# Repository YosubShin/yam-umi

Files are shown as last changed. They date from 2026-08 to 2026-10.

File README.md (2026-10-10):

# YAM-UMI

An open-source, hand-worn [UMI](https://umi-gripper.github.io/)-style data
collection device for the **[I2RT YAM](https://i2rt.com/products/yam-6-dof-arm)
arm's linear gripper**.

> **Paper and video:**
> [YAM-UMI: A Fiducial-Tracked Glove that Collects Metrically Labelled Demonstrations for the YAM](paper/main.pdf) (preprint) ·
> [2.5-minute video](media/yam-umi-paper-video.mp4) ·
> [LaTeX source and figures](paper/)

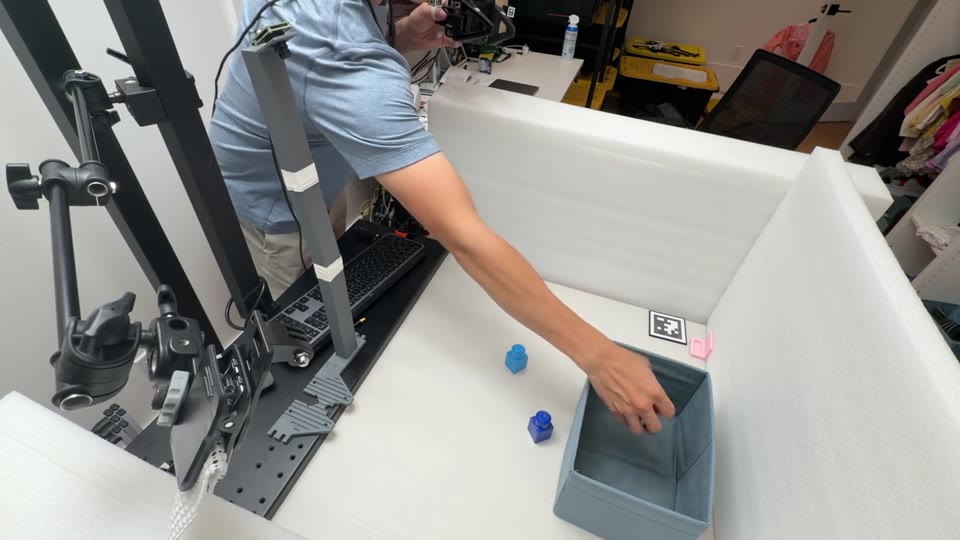
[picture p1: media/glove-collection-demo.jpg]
Glove collection demo with YAM-UMI and experimental tracking accessories


*Watch the [glove collection demo](media/glove-collection-demo.mp4) (63 seconds,
9.4 MB). This setup combines the YAM-UMI gripper with
[forward-cam-umi](https://github.com/YosubShin/forward-cam-umi) marker tails,
the optional dodecahedral wrist tracker, and a head-mounted camera.*

<p align="center">
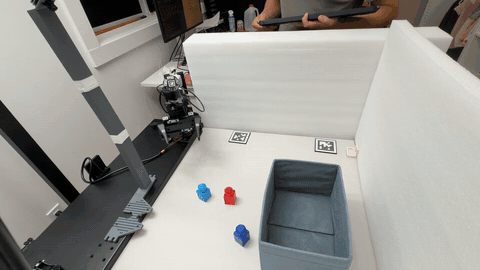
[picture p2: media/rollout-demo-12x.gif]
YAM-UMI rollout demo at 12 times normal speed
  
</p>
<p align="center"><em>Rollout demo at 12× speed (full sequence, about 20 seconds).
Watch the silent 720p video at <a href="media/rollout-demo-1x-720p.mp4">normal speed</a>
or <a href="media/rollout-demo-6x-720p.mp4">6× speed</a>.</em></p>

YAM-UMI is deliberately built for one arm.
It mirrors the YAM linear gripper's jaw geometry, reuses the YAM wrist camera
mount, and reproduces the gripper's own rail-and-pinion mechanism, so **the
camera pose relative to the gripper tips, and the way those tips move, are the
same during data collection as on the deployed robot**. Aperture is recovered
from fiducial markers rather than a servo encoder, so there is no motor to
backdrive and no loaded plastic linkage to fail.

<p align="center">
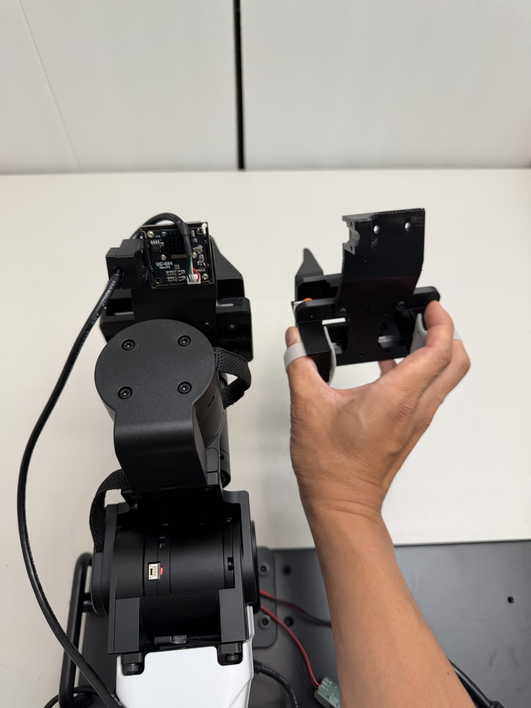
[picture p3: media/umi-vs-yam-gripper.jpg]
The YAM arm's linear gripper beside the YAM-UMI handheld device, showing matched jaw geometry and the same wrist camera mount
  
</p>
<p align="center"><em>Left: the YAM arm's gripper. Right: YAM-UMI. Same jaw geometry,
same camera mount, same tips — so the wrist camera sees the same thing in both.</em></p>

<p align="center">
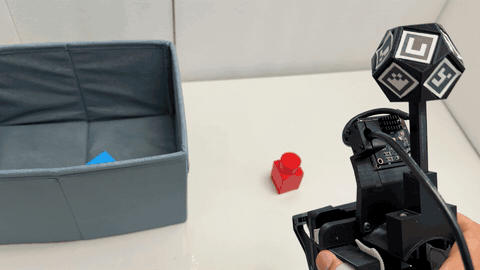
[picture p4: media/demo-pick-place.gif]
Operator performing a pick-and-place with the YAM-UMI gripper, dodecahedral tracker visible above the wrist
  
</p>
<p align="center"><em>Pick-and-place demonstration, with the dodecahedral wrist tracker
attached. Full quality: <a href="media/demo-pick-place.mp4">demo-pick-place.mp4</a>.</em></p>

> **Status: hardware released, pipeline in progress.** The mechanical design is
> printed and assembled, and the optional wrist tracker is characterised for
> settled holds (0.46 mm RMS). End-to-end data collection and policy training with
> this device have not been run yet, and the parity claims below are by
> construction rather than measured — see
> [Status and limitations](#status-and-limitations).

## Why another UMI variant

The point of a UMI-style rig is to collect demonstrations without a robot in the
loop, then train a policy that consumes wrist-camera images. That only works if
what the camera sees at collection time resembles what it sees at deployment
time.

That principle is UMI's own, not this project's. The
[UMI paper](https://arxiv.org/abs/2402.10329) states it directly — *"When
deploying UMI on a robot, we place GoPro cameras with the same location with
respect to the same 3D-printed fingers as on the hand-held gripper"* — and reports
wrist-camera video that is "almost indistinguishable" between demonstration and
deployment.

What differs between designs is the **direction** in which the match is made. UMI
adapts the robot to the interface: mount UMI's fingers and a GoPro on any arm with
a parallel jaw stroke over 85 mm, and the match follows. YAM-UMI adapts the
interface to the robot: the arm keeps its stock gripper tips and stock camera
mount, and the handheld device changes to match. That direction suits a fleet
already standardized on one arm, or a deployment configuration you would rather
not modify — at the cost of fitting nothing else.

This design began as an attempt to use
[HandUMI](https://github.com/murobotics-ai/handumi-hw) on a YAM. HandUMI is one
of the few open hand-worn UMI designs whose linkage keeps the two jaws
**synchronized**, moving together the way a parallel gripper does rather than
independently following the operator's two fingers. For anyone targeting a linear
gripper that property is the hard part, and it made HandUMI the natural starting
point here. Two things kept it from working on a YAM.

### 1. The camera extrinsic could not be matched

HandUMI takes a third position: rather than adapting either side, it keeps one
shared body across arms and swaps only the gripper tips, leaving the rest to
software retargeting. That is what lets a single rig serve an AgileX Piper, an ARX
X5, a Trossen WidowX and others — but it means the wrist camera sits where the
shared body allows, and its mount does not readily adjust to reproduce the YAM
camera's angle relative to the gripper tips. The resulting viewpoint shift is a
domain gap the policy has to absorb.

YAM-UMI instead reuses the YAM gripper's own fisheye camera mount on a body that
reproduces the YAM jaw geometry, so the camera-to-tip transform is matched by
construction rather than corrected in software. Because the device also accepts
the **actual gripper tips that ship with the YAM arm**, the jaws occlude the same
part of the frame, the aperture-to-pixel mapping is the same, and the contact
patch on the object is the same.

The cost is generality: this rig targets the YAM linear gripper and nothing else.
That is a deliberate trade, not an oversight.

### 2. The servo and the lever linkage

HandUMI measures aperture with a Feetech servo encoder, which gives a clean
per-frame width signal. The operator pays for it by backdriving the servo through
its gear train on every pinch, adding friction to the one motion the device
exists to record faithfully.

The linkage was the more immediate problem. In hand, its printed lever parts
popped out of the mechanism under normal use — the load path runs through
printed plastic links, and that is where it failed.

YAM-UMI carries the motion on two MGN9 linear rails instead, with a single pinion
between two racks — one rack per jaw — to keep the jaws synchronized.

**This is the mechanism the YAM gripper itself uses.** Two MGN9 rails, two racks,
and a pinion is not an arbitrary alternative to the crank linkage; it is what is
inside the robot's own linear gripper. So the parity here is not only optical and
geometric but *kinematic*: the jaws travel the way the robot's jaws travel, the
aperture is symmetric about the same centerline, and the relationship between the
operator's pinch and the resulting width is the one the robot can actually
execute. There is no mechanism-level retargeting between collection and
deployment, because there is no mechanism difference to retarget.

Aperture is read from fiducial markers on the tips, the approach the original UMI used.
Consequences:

- **No backdrive friction.** The pinch is governed by the rails and the
  rack-and-pinion coupling only.
- **No servo, controller, or power supply** in the bill of materials, and no
  cable routing for them.
- **No loaded lever linkage.** The printed parts are brackets and mounts, not
  structural links carrying the pinch load.

<p align="center">
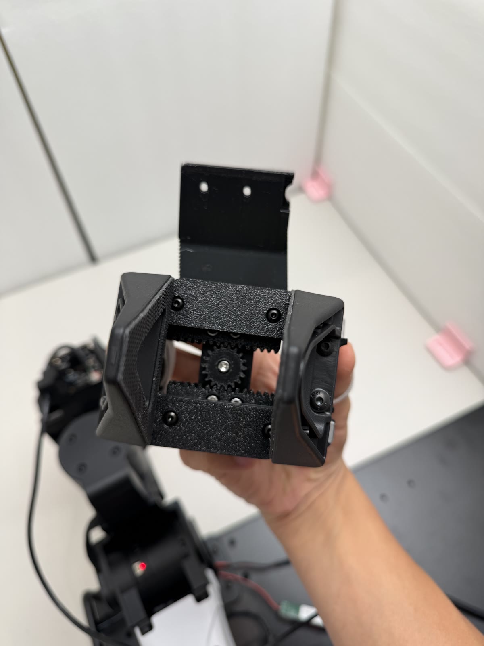
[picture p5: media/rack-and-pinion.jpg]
View from the gripper tip side: a central pinion meshing with a rack on each jaw, keeping the two jaws synchronized
  
</p>
<p align="center"><em>Viewed from the tip side: one pinion between two racks, one rack
per jaw, riding two MGN9 rails — the same arrangement as inside the YAM arm's own
linear gripper. A single-handed pinch drives both jaws symmetrically, with no
servo in the loop and no linkage carrying the load.</em></p>

## What it records

| Signal | Source |
|---|---|
| Wrist pose, SE(3) | Camera SLAM from the wrist fisheye — the original UMI approach, and the default here. Optionally, a dodecahedral ArUco marker ball observed by an external camera |
| Gripper aperture | 6 mm AprilTag (16h5) markers on the gripper tips, seen by the wrist fisheye camera |
| Wrist-view video | Fisheye USB camera on the YAM camera mount |

SLAM is the default because it keeps collection portable, which is the whole
point of a UMI-style rig. The visual-inertial SLAM path does not need the
marker-ball assembly; the wrist-camera tip markers are still used to measure
aperture.

### Optional: dodecahedral wrist tracker

If your setup can accommodate a fixed external camera, this repository also
includes a dodecahedral marker ball and the mounts that attach it to the gripper.
It buys precision at the cost of confining collection to the camera's view.

Measured with the ball at roughly 94 cm standoff, **on settled holds**:

| Metric | Result |
|---|---|
| Within-hold precision | 0.46 mm RMS (median), p90 0.68 mm |
| Revisit repeatability | 0.08–0.17 mm SD per axis (lateral 0.12, depth 0.17) |

Coverage — the fraction of frames with enough faces visible to solve a bundle
pose — depends strongly on the external camera:

| Camera | ≥1 face | ≥2 faces | ≥3 faces |
|---|---|---|---|
| Sony (4K 30p, H.264) | 100% | 90.8% | 77.5% |
| Arducam B0591 (1080p, focus locked via v4l2) | 79.6% | 68.3% | 59.1% |

**Update (2026-09):** both of the original caveats — settled-holds-only, and
absolute pose unresolved — have since been resolved by measuring this same
ball design on the real YAM arm against its joint encoders. During full-speed
teleoperated manipulation (30 episodes, ~23k frames), fused-ball pose agrees
with the robot's forward kinematics to **7.7 mm median / 22.7 mm p95 / 1.7°**
at a tool point 13 cm from the ball, with pose solved in 98.5% of frames;
the error budget is dominated by the hand-eye calibration (4.8 mm residual),
not the camera. The earlier 14%/9° discrepancies were extrinsics error, fixed
by a proper `calibrateRobotWorldHandEye` solve harvested from ordinary
episodes. Full numbers, method, and known failure modes:
[`pos-tracking/dynamic-accuracy.md`](pos-tracking/dynamic-accuracy.md).

The Arducam coverage was measured before any mount or field-of-view tuning for that
camera, so it is a floor rather than a verdict on cheaper webcams.

See [`pos-tracking/README.md`](pos-tracking/README.md) for the build and
calibration procedure.

The third-party [tinyumi Quest-controller mount](https://github.com/vovw/tinyumi/blob/main/pos-tracking/quest_mount/handumi_v1/README.md)
provides an alternative pose source. It requires that fork's revised base plate
and mounting hardware and has not been tested by the YAM-UMI authors.

## Design updates

### 2026-09-28 — L bracket v4 and handle v14

- Updated the L bracket to mitigate plate bending when squeezing the glove hard.
- Changed gripper fastening from M4 bolts and nuts to M4 screws with heat-set
  inserts to make assembly easier.
- Updated the [STEP](hardware/STEP/L_bracket_v4.step) and
  [STL](hardware/STL/L_bracket_v4.stl) files, replacing v3.
- Updated the handle to v14, removing the side hole for an M4 nut. The handle
  attaches to the L plate with an M3 screw and heat-set insert; the remaining
  M4 hole serves only to prevent the handle from rotating in place.
  Updated the [STEP](hardware/STEP/handle_v14.step) and
  [STL](hardware/STL/handle_v14.stl) files, replacing v13.

## Parts

### Gripper body — [`hardware/`](hardware/)

Printed parts are provided as STEP and STL. The STEP files are the source of
truth; the STLs were tessellated from them at 0.05 mm chordal tolerance and are
watertight, so re-export from STEP if you want a different resolution.

| Part | Size (mm) | Role |
|---|---|---|
| `plate_v6` | 102 × 65 × 10.4 | Main plate; carries both linear rails, the camera arm, and the pinion axle |
| `adapter_v10` | 50 × 25.9 × 10.6 | Carriage-to-jaw adapter; presents the YAM gripper tip interface |
| `pinion_z18_deep_v0`–`v3` | ⌀20.0–19.7 × 10.6 | Module 1, z=18 spur pinion coupling the two jaw racks for symmetric motion, as in the YAM gripper. Four fit variants — see [Printing](#printing) |
| `handle_v14` | 32 × 17 × 55 | Operator handle |
| `L_bracket_v4` | — | Camera arm bracket |
| `YAM_linear_gripper_fisheye_camera_mount` | — | Fisheye camera mount, matching the YAM wrist camera pose |

<!-- TODO: confirm the Role column. The pinion/rack coupling is confirmed by the
     tip-side photo, but the plate, adapter, handle and bracket roles are still
     inferred from geometry rather than from your notes. -->

**Gripper tips are not printed.** Use the "Linear 4310" tips that ship with the
YAM arm — that is what makes the contact geometry identical to deployment. If you
do not have spares, I2RT sells them as
[Gripper Tips (for Linear-Gear Style Gripper)](https://i2rt.com/products/gripper-tips-for-linear-gear-style-gripper)
($69), though they are frequently out of stock.

### Position tracking — [`pos-tracking/`](pos-tracking/)

See [`pos-tracking/README.md`](pos-tracking/README.md) for marker specifications
and printing instructions.

- `wrist_dodecahedron_marker/` — the dodecahedral marker ball (51 mm across),
  its stalk, arc adapter, and extender.
- `glove_markers_v4.pdf` — the marker sheet: 15 mm ArUco markers for the ball
  and the 6 mm AprilTag tip markers used for aperture sensing from the wrist
  fisheye camera.

Marker placement on the ball is not prescribed: stick the eleven markers on in
any arrangement and recover the face-to-ID mapping by calibration. That absorbs
print-and-stick tolerances instead of baking them in as permanent error, but it
also means each ball's calibration is specific to the unit it was measured on.

The marker sheet also carries tail and base markers for
[forward-cam-umi](https://github.com/YosubShin/forward-cam-umi), which provide
occlusion backup and external-camera aperture measurements. These require
additional printed parts; see
[optional forward-camera extensions](pos-tracking/README.md#optional-forward-camera-extensions).

## Build

- [Bill of materials](bom/README.md) — ~$79 per gripper in parts, plus shop supplies (filament, fastener kits, tape) if you are starting from nothing.
- [Assembly](docs/assembly.md) — build order and fastener placement.

### Printing

Everything was printed in **PETG** on a Bambu Lab X2D with the stock PETG profile
and *Support for PLA/PETG* enabled. No part needed tuning beyond support
settings. PLA should work too — nothing here runs warm and it is an indoor,
hand-held device — PETG is simply what these were printed in.

**The pinion comes in four variants.** `pinion_z18_deep_v0`–`v3` are the same
18-tooth, module-1 pinion at descending outside diameter — 20.0, 19.9, 19.8 and
19.7 mm — a 0.1 mm clearance ladder against the racks. **Print all four on one
plate and pick the one that runs smoothest** in your assembly. Printer, filament
and insert alignment all shift the effective fit, so the right variant is
empirical rather than predictable; `v3` was the best fit in the reference build,
but choose the variant that runs most smoothly on your unit.

## Status and limitations

- **Glove collection and training:** the companion
  [forward-cam-umi workflow](https://github.com/YosubShin/forward-cam-umi/blob/main/scripts/README.md)
  reports four glove sessions (about 70 episodes) recorded, solved, built into
  training datasets, and used for training. Camera-extrinsic parity remains a
  separate claim that has not been validated against recorded imagery.
- **Wrist tracker: settled-hold precision 0.46 mm RMS at ~94 cm; dynamic
  tracking and absolute robot-frame pose are now certified** (7.7 mm median
  agreement with the arm's forward kinematics across full-speed
  manipulation) — see
  [`pos-tracking/dynamic-accuracy.md`](pos-tracking/dynamic-accuracy.md).
- **Camera and glove-marker calibration:** commands for camera intrinsics,
  ball geometry, and gripper-marker geometry are published in
  [forward-cam-umi](https://github.com/YosubShin/forward-cam-umi/blob/main/scripts/README.md).
  Robot-side hand-eye calibration and dataset construction require the robot's
  kinematics and are separate from this assembly.
- **Aperture accuracy is unmeasured.** A comparison of fiducial-derived width
  against the YAM encoder, or against calipers over a swept aperture, would be
  the most valuable single addition to this repo.
- **Fiducial occlusion** is an inherent failure mode; there is no fallback width
  estimate when markers are lost.
- **Single-arm scope.** No support for other grippers is planned.

## Related work

- **[UMI](https://umi-gripper.github.io/)** (Chi et al.,
  [arXiv:2402.10329](https://arxiv.org/abs/2402.10329)) — the original handheld
  gripper, the source of both the fiducial-based aperture sensing this design
  returns to and the principle of minimizing the observation embodiment gap.
  UMI achieves that match by mounting its own fingers and camera on the robot;
  YAM-UMI reverses the direction.
- **[HandUMI](https://github.com/murobotics-ai/handumi-hw)** (Murobotics) — the
  direct starting point for this work, and one of the few open hand-worn UMI
  designs with a synchronized parallel-jaw mechanism. YAM-UMI takes the
  glove-style form factor and the hook-and-loop finger retention from it, and
  diverges on camera placement, jaw mechanism, and aperture sensing for the
  reasons above. If you want a robot-agnostic rig rather than a YAM-specific one,
  or a direct encoder reading of aperture, HandUMI is the better fit. No HandUMI
  CAD is used here.
- **[Generalist](https://generalistai.com/)** — the wearable data-collection
  approach HandUMI credits as its own motivation.

### The robot this targets

- **[YAM 6-DOF arm](https://i2rt.com/products/yam-6-dof-arm)** (I2RT Robotics) —
  the arm YAM-UMI is built for. 6 DOF, 2 kg payload, 95 mm gripper throw.
- **[YAM documentation](https://doc.i2rt.com/products/yam)** — specifications and
  setup for the arm and its linear gripper.
- **[`i2rt-robotics/i2rt`](https://github.com/i2rt-robotics/i2rt)** — the Python
  client library, URDF, and robot meshes. The meshes there are what this design's
  gripper geometry and camera mount are dimensioned from; see
  [THIRD_PARTY_NOTICES.md](THIRD_PARTY_NOTICES.md).

## License and attribution

This project is released under the [MIT License](LICENSE).

Geometry in this repository is dimensioned from mesh files published by I2RT
Robotics under the MIT License. See
[THIRD_PARTY_NOTICES.md](THIRD_PARTY_NOTICES.md) for the full attribution.

**This project is not affiliated with, endorsed by, or sponsored by I2RT
Robotics.** "YAM" is used only to identify the robot arm this hardware is
designed for.

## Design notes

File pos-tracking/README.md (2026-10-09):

# Position tracking

**This is an optional add-on.** The default way to recover wrist pose with
YAM-UMI is camera SLAM from the wrist fisheye, the same approach the original UMI
used, with visual-inertial SLAM. It needs no marker-ball hardware and keeps
collection portable. The wrist-camera aperture markers described below are
still needed to measure jaw opening.

What is here is a **dodecahedral ArUco marker ball** on a stalk, observed by an
external forward-facing camera, for setups that can accommodate a fixed camera.
It measures sub-millimetre on settled holds (numbers below), at the cost of
confining collection to that camera's view. Ball markers use the
**`DICT_4X4_100`** dictionary, IDs 25–35; IDs 36–49 are for the
forward-camera extension described below. IDs 0–24 are reserved for the
robot-mounted ball used to validate tracking against forward kinematics (see
[forward-cam-umi](https://github.com/YosubShin/forward-cam-umi)).

<p align="center">
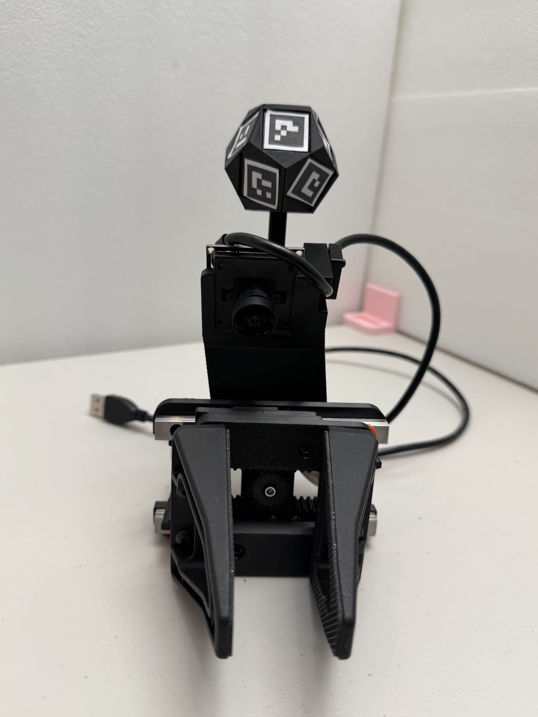
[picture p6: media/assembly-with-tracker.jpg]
The assembled YAM-UMI gripper with the dodecahedral ArUco marker ball mounted on its wrist stalk
  
</p>
<p align="center"><em>The assembled gripper with the dodecahedral tracker on its
stalk, held clear of the hand and of the fisheye camera's view.</em></p>

## Parts

| Part | Size (mm) | Notes |
|---|---|---|
| `dodeca_marker_ball_v2` | 51.05 across | Regular dodecahedron; carries the 15 mm markers |
| `stalk_rod_80mm` | 8 × 8 × 80 | Rod holding the ball clear of the hand |
| `wrist_stalk_arc_adapter` | 44 × 14 × 49.8 | Mounts the stalk to the wrist |
| `arc_extender` | 43.5 × 41.5 × 57 | Extends the arc mount |

A dodecahedron is used so that at least one face is well-conditioned for pose
estimation from any viewing direction, which removes the orientation blind spots
a single planar marker has.

## Markers

`glove_markers_v4.pdf`, group *dodecahedron ball*: **nominal 15 mm black
squares on 19.5 mm tiles, IDs 25–35**, applied to eleven faces of the ball.
Use measured black-square sizes for calibration.

The basic wrist-camera-and-ball assembly uses the sheet's left column:
the *dodecahedron ball* group and the *tips WRIST* group
([below](#aperture-markers)).

### Optional forward-camera extensions

The right-hand column contains the *tails* (BACK, TOP, FORWARD, OUTSIDE,
BOTTOM) and *base* (BACK, TOP) groups, IDs 36–49. They belong to the
[forward-cam-umi extensions](https://github.com/YosubShin/forward-cam-umi):
extra markers and printed parts provide an occlusion backup for the ball
and let the external camera measure aperture. They are not required for
the basic wrist-camera-and-ball assembly. Follow the companion repository
if using those extensions; both projects share this sheet so the marker
IDs do not collide.

### Measure and prepare the markers

Print at **100% / Actual size** on matte paper or label stock, disabling
all automatic scaling. Before cutting, check the 100 mm bar and take
**six black-square measurements per group**, across different markers and
alternating width and height. Average and record each group separately;
the white border is the cutting boundary, not the measurement boundary.
Enter the measured sizes in the unit's marker map and use the measured
ball size in its calibration. See the assembly guide's
[measurement procedure](../docs/assembly.md#measure-before-you-cut--every-marker-group).

Apply thin double-sided tape across the **entire back of the uncut marker
region**, then cut through paper and tape together, preserving the white
border. Bond every edge flat. Do not use glue, glossy paper, or tape over
the printed face: curled edges and reflections interfere with corner
detection. The same preparation applies to ball, finger, and extension
markers.

### Marker placement is not prescribed

There is deliberately **no face-to-ID mapping to follow**. Apply the eleven
markers to the faces in any arrangement, then recover the layout by
running the assembled ball through a solver that estimates each marker's pose in
the ball's body frame from observations across many viewpoints.

This is worth understanding before you build: the ball's geometry is calibrated,
not assumed. It means print-and-stick tolerances are absorbed by the calibration
rather than becoming permanent error, and it means **your ball's mapping will
differ from anyone else's** — the calibration output is specific to the physical
unit you built and has to travel with it.

Follow [forward-cam-umi steps 2–6](https://github.com/YosubShin/forward-cam-umi/blob/main/scripts/README.md)
for camera setup, intrinsics, a rotation take, detection, and ball geometry
solving. Use the measured marker size and keep the solved geometry with
that physical ball. Moving, re-sticking, or swapping a marker requires
recalibrating it. The assembly guide summarizes the
[camera and calibration sequence](../docs/assembly.md#the-forward-camera-mount-focus-calibrate-solve-the-ball).

### Measured performance

All figures below were taken with the ball at roughly 94 cm standoff from the
external camera, **on settled holds**.

**Precision**

| Metric | Result |
|---|---|
| Within-hold | 0.46 mm RMS (median), p90 0.68 mm |
| Revisit repeatability | 0.08–0.17 mm SD per axis (lateral 0.12, depth 0.17) |

**Coverage** — the fraction of frames with enough faces visible to solve a bundle
pose. This is where the choice of external camera shows up:

| Camera | ≥1 face | ≥2 faces | ≥3 faces |
|---|---|---|---|
| Sony (4K 30p, H.264) | 100% | 90.8% | 77.5% |
| Arducam B0591 (1080p, focus locked via v4l2) | 79.6% | 68.3% | 59.1% |

The B0591 numbers were measured before any mount or field-of-view tuning for
that camera. The 15 mm faces give it comfortable pixels at this range, so the
gap to the Sony is a field-of-view and mounting difference rather than a
sensor limit — treat 68% as a floor, not a verdict on cheaper webcams.

#### The camera that ended up winning: Arducam B0587 (4K low-light)

After the table above we moved to the **Arducam B0587** (4K STARVIS2 sensor,
~88° FOV, UVC/MJPEG) and it became the workhorse — it is the camera behind
every number in [`dynamic-accuracy.md`](dynamic-accuracy.md):

| Metric | Result |
|---|---|
| ChArUco intrinsics | 0.744 px RMS at 4K |
| Rigid marker-pair RMS (best pairs) | 0.7 mm |
| Detection vs arm speed | flat to 3 m/s — no measured ceiling |
| Per-frame ≥1-face detection, full teleop session | 99.97% |

**Why it works — the motion-blur unlock.** Fiducial tracking during motion
dies by corner smear, not by frame rate: at 25 fps a marker moving 1 m/s
travels 40 mm between frames, but what kills the *decode* is how far it moves
during the *exposure*. The recipe is a very fast shutter on a sensor that can
afford it:

- **Exposure 0.2 ms** (`exposure_time_absolute=2`, manual mode, gain 0,
  sharpness 0). At 0.2 ms, even 3 m/s of motion smears only 0.6 mm —
  sub-pixel at ~1 m standoff — so the corner detector simply never sees
  blur, and the speed ceiling disappears.
- **A low-light sensor makes that exposure usable.** 0.2 ms under ordinary
  indoor lighting starves a typical webcam sensor; the STARVIS2's
  sensitivity yields clean, zero-gain images at that shutter in a bright
  lab. This pairing — fast shutter *enabled by* low-light silicon — is the
  whole trick, and it is worth selecting cameras for explicitly. (In dim,
  ceiling-light-only conditions the same camera certified at 1 ms +
  gain 20 with equivalent tracking quality.)

Hard-won caveats that travel with this camera class:

1. **Control readback lies.** UVC exposure writes are accepted and read
   back correctly *whether or not the imaging pipeline latched them* — and
   on some modules they only latch after streaming has started. Apply the
   settings mid-stream and verify **behaviourally**: wave a hand in front
   of the lens; at 0.2 ms it must be frozen, not smeared. We lost a full
   session to trusting readback before learning this.
2. **Image brightness is not an exposure probe** on HDR/tone-mapping ISPs —
   some modules normalise brightness toward a target regardless of the real
   exposure. Streaks and blur are the probe; brightness is not.
3. **Some modules' `focus_absolute` is accepted but inert** (the B0587
   focuses by physically rotating the barrel only). Verify focus with a
   live sharpness meter, then mechanically lock the barrel with a witness
   mark — and recalibrate intrinsics after *any* barrel movement.
4. **Flickering LED lighting strobes at sub-millisecond shutters.** Room
   light that looks steady to the eye can beat against a 0.2 ms exposure;
   use DC or high-frequency-driven lighting for the capture volume.

#### Locking focus on the external camera

**Lock the external camera's focus before calibration and collection.**
Refocusing changes the imaging parameters used by the pose solver.

The **B0587** focuses mechanically: rotate the lens barrel while viewing the
live meter in [focus_tune.py](https://github.com/YosubShin/forward-cam-umi/blob/main/scripts/focus_tune.py),
then mark the barrel and leave it fixed. Its `focus_absolute` control can be
accepted without changing focus; do not rely on that control for this module.

For an **autofocus module such as the B0591** used in the earlier coverage
measurement, disable autofocus and lock a fixed setting through V4L2 on Linux.
Control names differ across kernel and driver versions, so list them first:

```
v4l2-ctl -d /dev/video0 --list-ctrls
```

Then disable autofocus and pin a focus value, using whichever names appeared
(`focus_automatic_continuous` on newer uvcvideo, `focus_auto` on older):

```
v4l2-ctl -d /dev/video0 --set-ctrl=focus_automatic_continuous=0
v4l2-ctl -d /dev/video0 --set-ctrl=focus_absolute=<value>
```

Pick the value by focusing on the ball at your working standoff, reading back
`focus_absolute`, then setting it explicitly. These controls reset when the device
is replugged, so reapply them at the start of every session — or with a udev rule
— and re-run the camera calibration if the focus value ever changes.

#### What these numbers do and do not support

1. **Settled holds only** — *resolved 2026-09*: dynamic tracking has since
   been certified on the real arm at full manipulation speed; see
   [`dynamic-accuracy.md`](dynamic-accuracy.md). The 0.46 mm figure remains
   the settled-hold precision, consistent with the 0.7 mm rigid-pair RMS
   measured there.
2. **Relative, not absolute** — *resolved 2026-09*: the 14% scale / 9°
   direction discrepancies were extrinsics error, fixed by a proper
   robot-world hand-eye calibration; absolute robot-frame pose now agrees
   with forward kinematics to 7.7 mm median / 22.7 mm p95, with the
   hand-eye residual (4.8 mm) as the floor. Details and method in
   [`dynamic-accuracy.md`](dynamic-accuracy.md).

## Aperture markers

Gripper aperture is read from AprilTag markers on the gripper tips, seen by the
wrist fisheye camera. Both tip markers must decode to obtain a metric
aperture measurement for a frame; verify detection throughout opening and
closing before recording. These markers are also needed when wrist pose
comes from SLAM instead of the marker ball.

`glove_markers_v4.pdf`, group *tips WRIST*: **AprilTag 16h5 markers with
nominal 6 mm black squares on 8 mm tiles, IDs 2 (A) and 3 (B)**, one per tip.
They use a separate AprilTag family so they don't take IDs from the ArUco range. The markers have to stay
resolvable in the fisheye view, where the tips sit well off-axis and the
effective resolution is much lower than the sensor's nominal figure suggests.

Measure and prepare the finger group separately using the procedure above.
In the reference build, each marker sits on the **top of the finger,
30 mm from its root**, facing the wrist camera. Keep the entire tile flat
and both markers visible throughout the full opening. Check detection
with [tag_contrast.py](https://github.com/YosubShin/forward-cam-umi/blob/main/scripts/tag_contrast.py).
If repositioning a marker after calibration, repeat the affected geometry
and aperture calibration. See the
[assembly instructions](../docs/assembly.md#apply-the-gripper-tip-markers).

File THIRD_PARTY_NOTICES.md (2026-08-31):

# Third-Party Notices

This project incorporates or derives from third-party material. Each item below
lists what was used and the license it was used under.

## I2RT Robotics — YAM robot models and CAD

This design is dimensioned from three sets of files published by I2RT Robotics
for YAM owners:

- the **YAM URDFs**,
- the **camera mount CAD** for the linear-gear gripper, and
- the **gripper cable retainer**.

Together these are what make the gripper geometry and the wrist camera pose match
the deployed robot.

**Scope of what is derived.** I2RT's plate CAD is supplied as a single merged
mesh, so it provides overall form but no separable components. Everything in this
repository that is not the camera mount interface or the cable retainer was drawn
from scratch — `plate_v6`, `adapter_v10`, `L_bracket_v3`, `handle_v13`, the pinion
variants, and all of `pos-tracking/` are original work, dimensioned either
independently or by measuring the physical robot. The derived content is the
mounting geometry needed to make the camera pose and jaw interface match, not the
mechanism.

**Source.** These were taken from the CAD folder I2RT distributes to customers,
linked from the [YAM product page](https://i2rt.com/products/yam-6-dof-arm) and
hosted on
[Google Drive](https://drive.google.com/drive/folders/17en5gl898ILuapsgUwBkjy4y5SOWQhB2).
That folder carries no stated licence or terms of use.

**Licence status.** I2RT publishes the same designs, in mesh form, in their
open-source [`i2rt-robotics/i2rt`](https://github.com/i2rt-robotics/i2rt)
repository under the MIT Licence — including
`i2rt/robot_models/arm/yam/v1/` (URDFs and meshes),
`i2rt/robot_models/gripper/linear_4310/assets/d405/camera_bracket_for_D405_linear_4310_.stl`
and `.../Cable_holder.stl`. That MIT grant covers the files in that repository. It
is strong evidence that I2RT intends these designs to be openly used, but it is
not itself a licence for the separately distributed CAD folder, which is where the
geometry used here came from.

The MIT Licence text as published in that repository:

```
MIT License

Copyright (c) I2RT Robotics

Permission is hereby granted, free of charge, to any person obtaining a copy
of this software and associated documentation files (the "Software"), to deal
in the Software without restriction, including without limitation the rights
to use, copy, modify, merge, publish, distribute, sublicense, and/or sell
copies of the Software, and to permit persons to whom the Software is
furnished to do so, subject to the following conditions:

The above copyright notice and this permission notice shall be included in all
copies or substantial portions of the Software.

THE SOFTWARE IS PROVIDED "AS IS", WITHOUT WARRANTY OF ANY KIND, EXPRESS OR
IMPLIED, INCLUDING BUT NOT LIMITED TO THE WARRANTIES OF MERCHANTABILITY,
FITNESS FOR A PARTICULAR PURPOSE AND NONINFRINGEMENT. IN NO EVENT SHALL THE
AUTHORS OR COPYRIGHT HOLDERS BE LIABLE FOR ANY CLAIM, DAMAGES OR OTHER
LIABILITY, WHETHER IN AN ACTION OF CONTRACT, TORT OR OTHERWISE, ARISING FROM,
OUT OF OR IN CONNECTION WITH THE SOFTWARE OR THE USE OR OTHER DEALINGS IN THE
SOFTWARE.
```

I2RT Robotics has not reviewed or endorsed this project. See the non-affiliation
notice in the [README](README.md#license-and-attribution).

## HandUMI (Murobotics)

No CAD from [`murobotics-ai/handumi-hw`](https://github.com/murobotics-ai/handumi-hw)
is used in this repository. HandUMI was the direct starting point for this work
and is credited as prior art. The design ideas adopted here are the hand-worn,
glove-style form factor, retaining the operator's fingers with hook-and-loop
straps, and keeping the two jaws mechanically synchronized — implemented
independently with a rack-and-pinion on linear rails rather than HandUMI's crank
linkage. HandUMI is licensed under Apache License 2.0.

## Universal Manipulation Interface (UMI)

No CAD from UMI is used here. UMI (Chi et al.) is the origin of the overall
approach, including fiducial-based gripper-aperture sensing, which this design
returns to. See <https://umi-gripper.github.io/>.

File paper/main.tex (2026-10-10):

\documentclass{article}

% Device-track application (CoRL 2026 workshop "The UMI Arena", Track 2):
% 2-4 pages + a 1-3 min video. Not double-blind: the device is brought in
% person. 'preprint' shows authors and drops the CoRL footnote.
\usepackage[preprint]{corl_2026}
\usepackage{graphicx}
\usepackage{booktabs}
\usepackage{xcolor}
\usepackage{siunitx}
\newcommand{\todo}[1]{\textcolor{red}{[#1]}}

\title{YAM-UMI: A Fiducial-Tracked Glove that Collects\\Metrically Labelled Demonstrations for the YAM}

\author{
  Yosub Shin \\
  University of Hawaii at Manoa \\
  \texttt{yosubs@hawaii.edu} \\
  \And
  Yuan Liu \\
  Independent \\
  \texttt{hiveyuan@gmail.com} \\
  \And
  Igor Molybog \\
  University of Hawaii at Manoa \\
  \texttt{molybog@hawaii.edu} \\
}

\begin{document}
\maketitle

%===============================================================================
\begin{abstract}
YAM-UMI is a glove-style UMI gripper that replicates the I2RT YAM linear gripper and is tracked by printed fiducials rather than an inertial camera: an 11-face ball on the back of the hand, seen by one fixed 4K camera over the workspace, gives the pose, and two tags in the jaws, seen by the glove's wrist fisheye, give the width. No IMU and no SLAM, so no drift: every label is an absolute per-frame measurement with a known error: the same stack mounted on the robot disagrees with the robot's kinematics by \SI{7.7}{mm} / \SI{1.7}{\degree} median, and policies trained on its labels instead of robot ground truth pay a constant \SI{14}{\percent} in validation loss. One person records 2.6--2.9 demonstrations per minute with the glove against 0.9--1.1 by teleoperation. Adding 165 glove episodes to 185 teleoperated ones lowers ACT's validation loss on the robot's held-out episodes (0.260 vs 0.295 forward camera, 0.236 vs 0.247 wrist) and in 30 paired rollouts per policy the co-trained wrist policy grasps the block as often as the teleop-only one (28/30 against 26/30), but the success rates of the co-trained and teleop-only policies are statistically indistinguishable (14/30 and 12/30 against 16/30, paired test); replacing half or three quarters of the teleoperated episodes with glove episodes at the same budget costs 33--37 points ($p<0.01$). Hardware and software are open; three units have been built from the files, one independently by a third party.
\end{abstract}
\begin{figure}[t]
  \centering
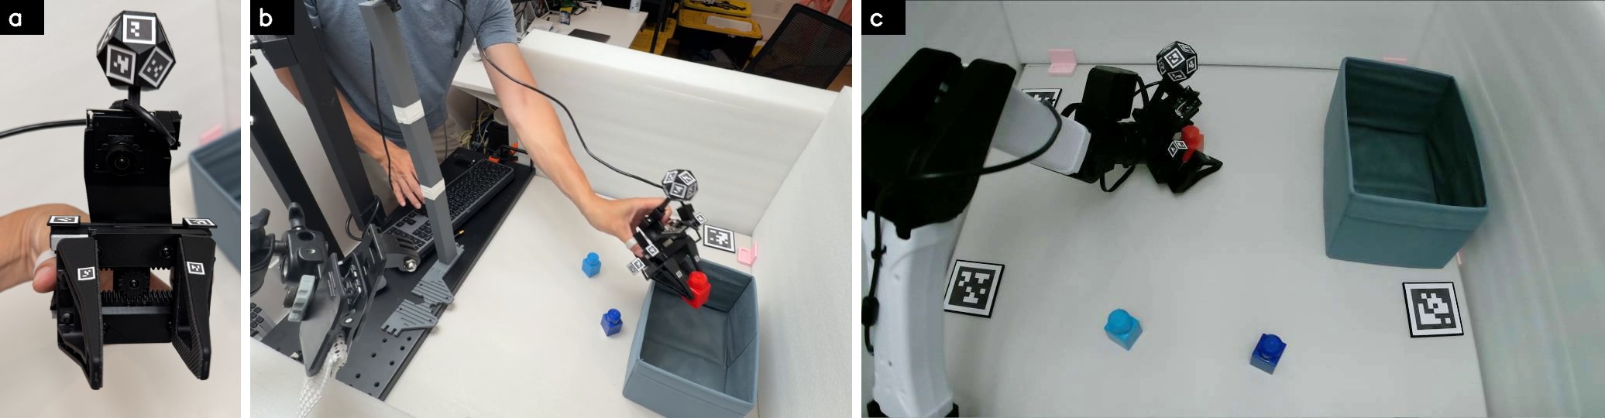
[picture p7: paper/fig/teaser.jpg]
  
  \vspace{1pt}
  {\footnotesize
  \begin{tabular}{@{}p{1.85cm}p{12.4cm}@{}}
    \toprule
    \textbf{Ergonomics} & \SI{355}{g} on the hand with cable (\SI{318}{g} without), under half of UMI's \SI{780}{g}; nothing to initialise. \\
    \textbf{Dexterity} & the YAM gripper's tasks (parallel-jaw pick, place, insert); \SI{0}{}--\SI{75}{mm} opening, robot's own fingers. \\
    \textbf{Strength} & \SI{1}{kg} by a jug handle, \SI{1.5}{kg} slips, \SI{2}{kg} no (robot: \SI{1.5}{kg}/\SI{2}{kg}); MGN9 rails, no wear in a month. \\
    \textbf{Reproducibility} & hardware and software open; one two-plate print, 7 purchased parts; three units built, one by others. \\
    \textbf{Cost} & \$79 per glove (\$22 without wrist camera); \$122 of shared rig; $\sim$\$200 per system vs UMI's \$371. \\
    \bottomrule
  \end{tabular}}
  \caption{(a) The glove: the robot's gripper fingers on a printed body, fiducial ball, marker cubes, wrist fisheye. (b) Collecting under the fixed 4K camera that labels the pose every frame. (c) A co-trained policy on the YAM, carrying the same ball that validated the labels. Below: the device against the workshop track's criteria.}
  \label{fig:teaser}
\end{figure}

%===============================================================================
\section{The device}
\label{sec:device}

\paragraph{Principle.}
The glove reproduces the robot's own parallel-jaw gripper \citep{i2rtyam}: the same \SI{95}{mm}-throw linear mechanism on two MGN9 rails, driven by a rack and pinion from a handle the operator squeezes, with the robot's own gripper fingers. All sensing is printed paper. A dodecahedral ball with eleven \SI{15}{mm} ArUco faces on the back of the hand gives the pose; two \SI{6}{mm} AprilTags in the jaws give the width to a wrist-mounted \SI{160}{\degree} fisheye; marker cubes on the jaws and four back markers keep the fixed camera tracking when the hand hides the ball at grasp. One Arducam B0587 4K camera over the workspace is the label camera and, for forward-observation policies, the policy camera too, so observation and pose label come from the same frame with nothing to synchronise; its exposure is locked at \SI{0.2}{ms}, so motion is frozen at any hand speed (tracked to \SI{0.67}{m/s} at the 99th percentile). The trade-off is that the workspace must be in the fixed camera's view (table-top tasks, where the policies are deployed anyway); in exchange, the pose labels are absolute in every frame and their error is measured against a robot (\S\ref{sec:results}).

\paragraph{Hardware and cost.}
Seven purchased parts make a glove for \$79: two MGN9 rail-and-carriage sets (\$20), bearings and straps (\$2), a \SI{160}{\degree} UVC fisheye (\$57), the YAM's own gripper fingers (shipped with the arm) and under \$2 of PETG and paper. The fixed camera on a printed mount is \$122 of rig that any number of gloves share --- about \$200 for a complete one-glove system, against \$371 for the reference UMI build (\$73 gripper, \$298 GoPro) \citep{chi2024umi}. A camera-free configuration with a SLAM pose is possible in principle but not built or tested here. The printed set fits in one two-plate job. The official fingers buy identical contact geometry and pad friction to the deployment gripper. Lifting a milk jug by its handle, the glove holds \SI{1.0}{kg} comfortably, lets \SI{1.5}{kg} slip and cannot lift \SI{2.0}{kg}; the robot with the same tips holds \SI{1.5}{kg} and just raises \SI{2.0}{kg}, its rating. The difference is material, not mechanism: a hard squeeze flexes the PETG plate where the robot's milled body does not.

%===============================================================================
\section{From a session to a dataset}
\label{sec:pipeline}
\paragraph{Calibration, once per unit.}
Cameras are calibrated from 45 ChArUco views (\SI{0.6}{px} RMS at 4K); the ball's face layout and the jaw markers from a two-minute rotation take (\SI{0.52}{px} RMS); the width readings from four holds on caliper-measured spacers (\SI{0.9}{mm} holdout RMS). Every marker group is calipered and declared, since printers rescale by a few percent (a second unit differed by \SI{1}{\percent}); a pre-flight refuses a bad camera before every session.

\paragraph{Collecting and labelling.}
Cameras roll continuously and ENTER marks episode boundaries: thirty pick-and-place demonstrations take 10--12 minutes, 2.6--2.9 per minute at 8--11\,s each, against 0.9--1.1 per minute by teleoperation of the same task on the same arm. Every frame's pose is a fused PnP over all visible ball faces and back markers (\SI{1.3}{px} median reprojection) in the robot's base frame, via a hand-eye calibration solved once on the robot and a ball-to-flange transform built from matched fingertip markers, so glove demonstrations land in the robot's joint space by the same offline IK the robot-side labels use; width is the wrist-tip reading in the robot's actuator units. The result is a LeRobot dataset with the teleoperated corpus's keys and action space, so co-training is a one-line merge.

%===============================================================================
\section{Results}
\label{sec:results}
\paragraph{Label accuracy, measured on the robot.}
With the same ball on the YAM and its joint encoders as reference, a 30-episode session gives \SI{7.7}{mm} / \SI{1.7}{\degree} median error at a tool point \SI{13}{cm} from the ball (\SI{22.7}{mm} p95; \SI{98.5}{\percent} of frames solved; relative precision \SI{0.7}{mm} RMS, the rest hand-eye residual). Downstream, training ACT on fiducial labels instead of robot ground truth costs \SI{+14}{\percent} validation loss, the same at 50, 100 and 185 episodes (Fig.~\ref{fig:scaling}): the price of the labels is known and does not grow with scale.

\paragraph{Policies from glove data.}
Table~\ref{tab:policies} and Fig.~\ref{fig:scaling} compare ACT policies \citep{zhao2023act} trained with LeRobot \citep{lerobot2024} (one recipe, \SI{15}{Hz}, 50k steps) on teleoperated data, glove data and both, scored on the robot's held-out teleoperated episodes. Glove-only policies improve with glove data (0.94 $\to$ 0.87 over 50 $\to$ 165 episodes) but stay a domain apart; spot checks on the robot showed why: they moved 2.6$\times$ faster than teleoperation and released mid-carry, because of what the two corpora record for the gripper. Teleoperation stores the \emph{commanded} width --- on a block the operator commands 0.246 while the fingers stop at the block, so the policy learns to over-command and the finger pads squeeze --- whereas the glove can only store the \emph{measured} width, 0.335 on the same block with the same fingers, and a policy that reproduces it as a command merely touches the block. This is not a defect of the print, both use the YAM's own fingers, but a property of any UMI-style device, which has no command to record. Two data-level corrections, resampling the glove timeline to teleop pace and mapping measured width to the commanded value through the robot's own fiducial-to-command relation, cut the glove-only robot-validation loss by a third (0.867 $\to$ 0.593, 0.847 $\to$ 0.584); what remains is appearance, the hand in the forward view and the glove's fingers in the wrist view. With the paced corpus, adding the full glove set to the full teleoperated set lowers the robot-only loss on both arms (0.260 vs 0.295, 0.236 vs 0.247); at a fixed budget of 185 demonstrations the wrist arm pays \SI{8}{\percent} with half the teleoperation (0.267) and \SI{10}{\percent} with a quarter (0.271). The budget is counted in demonstrations, the unit of collection effort; paced glove episodes carry \num{299} frames against \num{362} for teleop, so it is within \SI{20}{\percent} of frame-matched.

\begin{table}[h]
  \centering
  \small
  \caption{ACT validation loss on the robot's 12 held-out teleoperated episodes (lower is better) and rollouts on the YAM: trials in which the block was grasped, and trials that ended in the bin. One recipe, best checkpoint. ``Paced'': glove corpus resampled to teleop pace with measured width mapped to the commanded value.}
  \label{tab:policies}
  \begin{tabular}{llccc}
    \toprule
    observation & training episodes & robot val & grasped & success \\
    \midrule
    wrist fisheye & glove 165, paced & 0.584 & --- & --- \\
    wrist fisheye & teleop 46 + glove 139, paced & 0.271 & 15/30 & 6/30 \\
    wrist fisheye & teleop 92 + glove 93, paced & 0.267 & 22/30 & 5/30 \\
    wrist fisheye & teleop 185 & 0.247 & 26/30 & \textbf{16/30} \\
    wrist fisheye & teleop 185 + glove 165, paced & \textbf{0.236} & \textbf{28/30} & 12/30 \\
    \midrule
    forward + fovea & glove 165, paced & 0.593 & --- & --- \\
    forward + fovea & teleop 185 & 0.295 & --- & --- \\
    forward + fovea & teleop 185 + glove 165, paced & \textbf{0.260} & 20/30 & 14/30 \\
    \bottomrule
  \end{tabular}
\end{table}

\begin{figure}[t]
  \centering
  
  \caption{Validation loss on the robot's held-out episodes vs training-set size. Ground-truth and fiducial labels differ by a constant \SI{14}{\percent}; native-pace glove data stays a domain apart and pacing closes a third of the gap; the full co-trained corpora land at or below teleop-only, the equal-budget mixes above it.}
  \label{fig:scaling}
\end{figure}

\begin{figure}[t]
  \centering
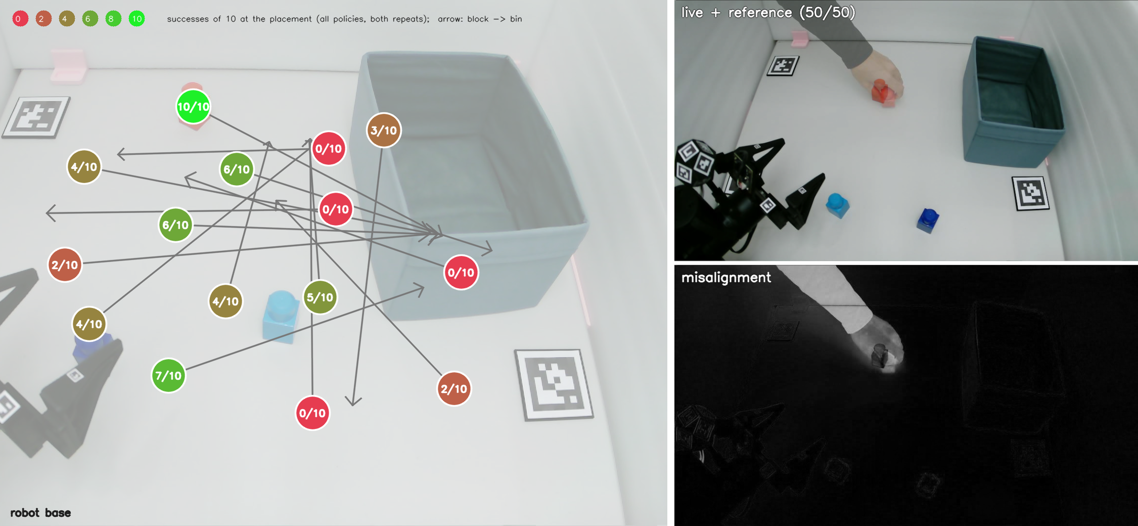
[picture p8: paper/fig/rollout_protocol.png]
  
  \caption{Rollout protocol. Left: the 15 placements (robot base bottom left); each disc is successes over all five policies and both repeats (of 10, red 0 to green 10); arrows point to each scene's bin. Right: before every trial the live view is blended with the scene's reference and shown as a misalignment image; the block is slid until the ghost disappears, so every policy and repeat meets the same scene to the pixel.}
  \label{fig:placements}
\end{figure}

\paragraph{Rollouts.}
Fifteen placements over the table, each run twice by every policy in shuffled order with the block re-placed to a saved reference (Fig.~\ref{fig:placements}), \SI{60}{s} budget, 30 trials per policy. The teleop-only wrist policy succeeds in 16/30 (Wilson 95\% CI 36--70\%); the co-trained policies in 14/30 (forward) and 12/30 (wrist), differences that are statistically indistinguishable from zero under the paired exact McNemar test ($p=0.77$, $0.29$). The two dilution policies succeed in 5/30 and 6/30, $-37$ and $-33$ points ($p=0.007$, $0.006$), losing in 7--8 of the 15 placements and winning one --- the opposite of what their validation losses, within \SI{10}{\percent} of the reference, suggest. What the loss does track is the grasp: across the four wrist policies, lower loss means more grasps, in rank order (15, 22, 26, 28 of 30); what it misses is the conversion from grasp to bin. The two repeats disagree in 7 of 75 policy--placement pairs, so outcomes are decided by the placement, and the effective sample is the 15 placements. Four placements at full reach were failed by every policy including the reference (success correlates with distance from the base, $\rho=-0.52$, not with carry length); the arms separate in the near two thirds, where three placements were solved by the co-trained policies and failed by the reference, and one by the reference alone.

The failure modes split by camera. The forward-camera co-trained policy fails by never grasping the block (10 of 16 failures) and is otherwise the fastest (median \SI{20.7}{s} to success against \SI{28.2}{s}; joint speed \SI{21}{\percent} higher) although it trained on the same paced episodes as the wrist mix, whose speed equals the reference's: the speed comes from the view. The wrist policies grasp and then drop the block: counting a grasp as partial success (Table~\ref{tab:policies}, ``grasped'') the co-trained policy and the half-teleop mix are level with the reference, but they convert 43\% and 23\% of their grasps into the bin against 62\%. Glove data helps the reach and close; what it costs is the hold. The wrist videos say how: in every successful carry of the co-trained wrist policy the bin stays in the fisheye's view, and in every drop it is out of view, after which the policy hesitates and commands the release (7 of 16 drops, against 2 of 10 for the reference, whose drops are slips with the jaws commanded shut). The teleop-only policy carries blind for up to \SI{4}{s}; the co-trained one has lost that. Two working hypotheses are: 1) the teleop policy bridges the blind stretch from joint state, which maps onto the bin consistently in teleoperated data but not in glove episodes, whose joint actions come from IK on a human hand path; 2) the paced corpus (one duplicated frame in four, human-speed motion blur) shifts the image distribution enough to cost it that habit.

%===============================================================================
\section{Limitations and what is next}
\label{sec:discussion}
Hardware \citep{yamumi2026} and software \citep{forwardcamumi2026} are open; a third party has built a unit and forked the design \citep{tinyumi2026}. The usable opening is \SI{75}{mm} of the \SI{86}{mm} mechanism, set by the span of thumb and fingers; the wrist cable can get in the way; a hard squeeze flexes the handle plate (the width label is measured, so unaffected); from one fixed viewpoint the hand hides the ball at grasp, hence the back markers (pose in 85\,\% of frames with them, 60\,\% without), and a head-worn second camera, once focused, solves it in \SI{99}{\percent} of frames. That points at what is next: we are testing whether the glove can lose its electronics altogether, with one head-worn camera as the only collection device --- no cables, nothing to synchronise --- labelling the glove from a moving viewpoint and doubling as the policy's input; the label stack already runs on head-camera footage \citep{forwardcamumi2026}.

%===============================================================================
\bibliography{refs}

\end{document}

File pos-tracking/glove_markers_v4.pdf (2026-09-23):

GLOVE rig | 4x4_100 IDs 25-49 + AprilTag 16h5 wrist tips (robot = same layout, 4x4 IDs -25)
PRINT AT 100% / ACTUAL SIZE, no fit-to-page. Verify 100mm bar with calipers BEFORE cutting. Cut on thin outline. TOP/BOTTOM-facing: MATTE paper.

dodecahedron ball - 15mm / 19.5mm tile

25 f0 | 26 f1 | 27 f2
28 f3 | 29 f4 | 30 f5
31 f6 | 32 f7 | 33 f8
34 f9 | 35 f10

tips WRIST (AprilTag 16h5) - 6mm / 8mm tile

16h5:2 A 16h5:3 B

tails BACK - 12mm / 16mm

36 A | 37 B

tails TOP - 12mm / 16mm

44 A | 45 B

tails FORWARD - 12mm / 16mm

48 A | 49 B

tails OUTSIDE - 12mm / 16mm

38 A | 39 B

tails BOTTOM - 12mm / 16mm

42 A | 43 B

base BACK - 12mm / 16mm

40 A | 41 B

base TOP - 12mm / 16mm

46 A | 47 B

bar = EXACTLY 100.0mm. Caliper one black square PER GROUP and declare that measured value in the config.

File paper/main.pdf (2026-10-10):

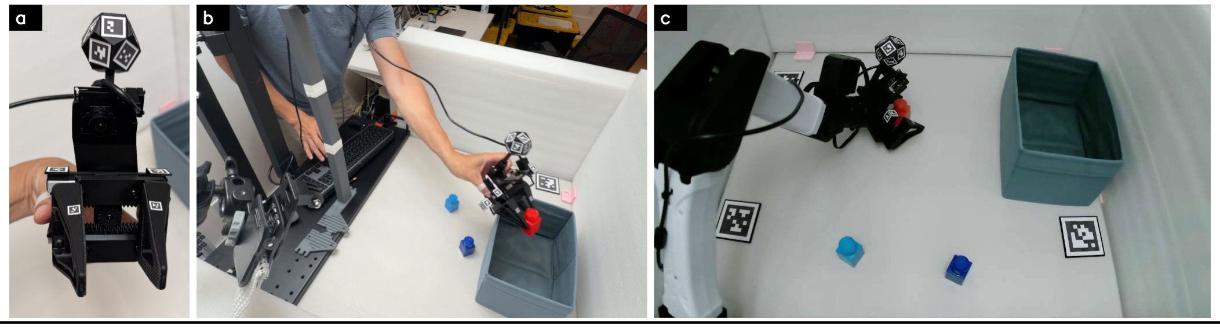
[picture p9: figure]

Ergonomics | 355 g on the hand with cable (318 g without), under half of UMI’s 780 g; nothing to initialise.
Dexterity | the YAM gripper’s tasks (parallel-jaw pick, place, insert); 0–75 mm opening, robot’s own fingers.
Strength | 1 kg by a jug handle, 1.5 kg slips, 2 kg no (robot: 1.5 kg/2 kg); MGN9 rails, no wear in a month.
Reproducibility hardware and software open; one two-plate print, 7 purchased parts; three units built, one by others.
Cost | $79 per glove ($22 without wrist camera); $122 of shared rig; ∼$200 per system vs UMI’s $371.

Figure 1: (a) The glove: the robot’s gripper fingers on a printed body, fiducial ball, marker cubes, wrist fisheye. (b) Collecting under the fixed 4K camera that labels the pose every frame. (c) A co-trained policy on the YAM, carrying the same ball that validated the labels. Below: the device against the workshop track’s criteria.

# YAM-UMI: A Fiducial-Tracked Glove that Collects Metrically Labelled Demonstrations for the YAM

Yosub Shin
University of Hawaii at Manoa yosubs@hawaii.edu

Yuan Liu
Independent
hiveyuan@gmail.com

Igor Molybog
University of Hawaii at Manoa molybog@hawaii.edu

Abstract: YAM-UMI is a glove-style UMI gripper that replicates the I2RT YAM linear gripper and is tracked by printed fiducials rather than an inertial camera: an 11-face ball on the back of the hand, seen by one fixed 4K camera over the workspace, gives the pose, and two tags in the jaws, seen by the glove’s wrist fisheye, give the width. No IMU and no SLAM, so no drift: every label is an absolute per-frame measurement with a known error: the same stack mounted on the robot disagrees with the robot’s kinematics by 7.7 mm / 1.7

- median, and
policies trained on its labels instead of robot ground truth pay a constant 14 % in validation loss. One person records 2.6–2.9 demonstrations per minute with the glove against 0.9–1.1 by teleoperation. Adding 165 glove episodes to 185 teleoperated ones lowers ACT’s validation loss on the robot’s held-out episodes (0.260 vs 0.295 forward camera, 0.236 vs 0.247 wrist) and in 30 paired rollouts per policy the co-trained wrist policy grasps the block as often as the teleop-only one (28/30 against 26/30), but the success rates of the co-trained and teleop-only policies are statistically indistinguishable (14/30 and 12/30 against 16/30, paired test); replacing half or three quarters of the teleoperated episodes with glove episodes at the same budget costs 33–37 points (p < 0.01). Hardware and software are open; three units have been built from the files, one independently by a third party.

### 1 The device

Principle. The glove reproduces the robot’s own parallel-jaw gripper [1]: the same 95 mm-throw linear mechanism on two MGN9 rails, driven by a rack and pinion from a handle the operator squeezes, with the robot’s own gripper fingers. All sensing is printed paper. A dodecahedral ball with eleven 15 mm ArUco faces on the back of the hand gives the pose; two 6 mm AprilTags in the jaws give the width to a wrist-mounted 160◦ fisheye; marker cubes on the jaws and four back markers keep the fixed camera tracking when the hand hides the ball at grasp. One Arducam B0587 4K camera over the workspace is the label camera and, for forward-observation policies, the policy camera too, so observation and pose label come from the same frame with nothing to synchronise; its exposure is locked at 0.2 ms, so motion is frozen at any hand speed (tracked to 0.67 m/s at the 99th percentile). The trade-off is that the workspace must be in the fixed camera’s view (table-top tasks, where the policies are deployed anyway); in exchange, the pose labels are absolute in every frame and their error is measured against a robot (§3).

Hardware and cost. Seven purchased parts make a glove for $79: two MGN9 rail-and-carriage sets ($20), bearings and straps ($2), a 160◦ UVC fisheye ($57), the YAM’s own gripper fingers (shipped with the arm) and under $2 of PETG and paper. The fixed camera on a printed mount is $122 of rig that any number of gloves share — about $200 for a complete one-glove system, against $371 for the reference UMI build ($73 gripper, $298 GoPro) [2]. A camera-free configuration with a SLAM pose is possible in principle but not built or tested here. The printed set fits in one two-plate job. The official fingers buy identical contact geometry and pad friction to the deployment gripper. Lifting a milk jug by its handle, the glove holds 1.0 kg comfortably, lets 1.5 kg slip and cannot lift 2.0 kg; the robot with the same tips holds 1.5 kg and just raises 2.0 kg, its rating. The difference is material, not mechanism: a hard squeeze flexes the PETG plate where the robot’s milled body does not.

### 2 From a session to a dataset

Calibration, once per unit. Cameras are calibrated from 45 ChArUco views (0.6 px RMS at 4K); the ball’s face layout and the jaw markers from a two-minute rotation take (0.52 px RMS); the width readings from four holds on caliper-measured spacers (0.9 mm holdout RMS). Every marker group is calipered and declared, since printers rescale by a few percent (a second unit differed by 1 %); a pre-flight refuses a bad camera before every session.

Collecting and labelling. Cameras roll continuously and ENTER marks episode boundaries: thirty pick-and-place demonstrations take 10–12 minutes, 2.6–2.9 per minute at 8–11 s each, against 0.9–1.1 per minute by teleoperation of the same task on the same arm. Every frame’s pose is a fused PnP over all visible ball faces and back markers (1.3 px median reprojection) in the robot’s base frame, via a hand-eye calibration solved once on the robot and a ball-to-flange transform built from matched fingertip markers, so glove demonstrations land in the robot’s joint space by the same offline IK the robot-side labels use; width is the wrist-tip reading in the robot’s actuator units. The result is a LeRobot dataset with the teleoperated corpus’s keys and action space, so co-training is a one-line merge.

### 3 Results

Label accuracy, measured on the robot. With the same ball on the YAM and its joint encoders as reference, a 30-episode session gives 7.7 mm / 1.7

- median error at a tool point 13 cm from the ball (22.7 mm p95; 98.5 % of frames solved; relative precision 0.7 mm RMS, the rest hand-eye residual). Downstream, training ACT on fiducial labels instead of robot ground truth costs 14 % validation loss, the same at 50, 100 and 185 episodes (Fig. 2): the price of the labels is known and does not grow with scale.

Policies from glove data. Table 1 and Fig. 2 compare ACT policies [3] trained with LeRobot
[4] (one recipe, 15 Hz, 50k steps) on teleoperated data, glove data and both, scored on the robot’s held-out teleoperated episodes. Glove-only policies improve with glove data (0.94 → 0.87 over 50 → 165 episodes) but stay a domain apart; spot checks on the robot showed why: they moved

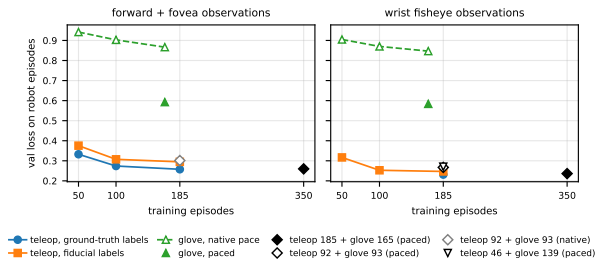
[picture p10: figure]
training episodes; val loss on robot episodes; forward + fovea observations; wrist fisheye observations; teleop, ground-truth labels teleop, fiducial labels; glove, native pace glove, paced; teleop 185 + glove 165 (paced) teleop 92 + glove 93 (paced); teleop 92 + glove 93 (native) teleop 46 + glove 139 (paced)

Figure 2: Validation loss on the robot’s held-out episodes vs training-set size. Ground-truth and fiducial labels differ by a constant 14 %; native-pace glove data stays a domain apart and pacing closes a third of the gap; the full co-trained corpora land at or below teleop-only, the equal-budget mixes above it.

2.6× faster than teleoperation and released mid-carry, because of what the two corpora record for the gripper. Teleoperation stores the commanded width — on a block the operator commands 0.246 while the fingers stop at the block, so the policy learns to over-command and the finger pads squeeze — whereas the glove can only store the measured width, 0.335 on the same block with the same fingers, and a policy that reproduces it as a command merely touches the block. This is not a defect of the print, both use the YAM’s own fingers, but a property of any UMI-style device, which has no command to record. Two data-level corrections, resampling the glove timeline to teleop pace and mapping measured width to the commanded value through the robot’s own fiducial-to-command relation, cut the glove-only robot-validation loss by a third (0.867 → 0.593, 0.847 → 0.584); what remains is appearance, the hand in the forward view and the glove’s fingers in the wrist view. With the paced corpus, adding the full glove set to the full teleoperated set lowers the robot-only loss on both arms (0.260 vs 0.295, 0.236 vs 0.247); at a fixed budget of 185 demonstrations the wrist arm pays 8 % with half the teleoperation (0.267) and 10 % with a quarter (0.271). The budget is counted in demonstrations, the unit of collection effort; paced glove episodes carry 299 frames against 362 for teleop, so it is within 20 % of frame-matched.

Table 1: ACT validation loss on the robot’s 12 held-out teleoperated episodes (lower is better) and rollouts on the YAM: trials in which the block was grasped, and trials that ended in the bin. One recipe, best checkpoint. “Paced”: glove corpus resampled to teleop pace with measured width mapped to the commanded value.

observation | training episodes | robot val | grasped | success
wrist fisheye | glove 165, paced | 0.584 | — | —
wrist fisheye | teleop 46 + glove 139, paced | 0.271 | 15/30 | 6/30
wrist fisheye | teleop 92 + glove 93, paced | 0.267 | 22/30 | 5/30
wrist fisheye | teleop 185 | 0.247 | 26/30 | 16/30
wrist fisheye | teleop 185 + glove 165, paced | 0.236 | 28/30 | 12/30
forward + fovea | glove 165, paced | 0.593 | — | —
forward + fovea | teleop 185 | 0.295 | — | —
forward + fovea | teleop 185 + glove 165, paced | 0.260 | 20/30 | 14/30

Rollouts. Fifteen placements over the table, each run twice by every policy in shuffled order with the block re-placed to a saved reference (Fig. 3), 60 s budget, 30 trials per policy. The teleop-only wrist policy succeeds in 16/30 (Wilson 95% CI 36–70%); the co-trained policies in 14/30 (forward) and 12/30 (wrist), differences that are statistically indistinguishable from zero under the paired exact McNemar test (p = 0.77, 0.29). The two dilution policies succeed in 5/30 and 6/30, −37 and −33 points (p = 0.007, 0.006), losing in 7–8 of the 15 placements and winning one — the opposite of what their validation losses, within 10 % of the reference, suggest. What the loss does track is the grasp: across the four wrist policies, lower loss means more grasps, in rank order (15, 22, 26, 28 of 30); what it misses is the conversion from grasp to bin. The two repeats disagree in 7 of 75


Figure 3: Rollout protocol. Left: the 15 placements (robot base bottom left); each disc is successes over all five policies and both repeats (of 10, red 0 to green 10); arrows point to each scene’s bin. Right: before every trial the live view is blended with the scene’s reference and shown as a misalignment image; the block is slid until the ghost disappears, so every policy and repeat meets the same scene to the pixel.

policy–placement pairs, so outcomes are decided by the placement, and the effective sample is the 15 placements. Four placements at full reach were failed by every policy including the reference (success correlates with distance from the base, ρ = −0.52, not with carry length); the arms separate in the near two thirds, where three placements were solved by the co-trained policies and failed by the reference, and one by the reference alone.

The failure modes split by camera. The forward-camera co-trained policy fails by never grasping the block (10 of 16 failures) and is otherwise the fastest (median 20.7 s to success against 28.2 s; joint speed 21 % higher) although it trained on the same paced episodes as the wrist mix, whose speed equals the reference’s: the speed comes from the view. The wrist policies grasp and then drop the block: counting a grasp as partial success (Table 1, “grasped”) the co-trained policy and the half-teleop mix are level with the reference, but they convert 43% and 23% of their grasps into the bin against 62%. Glove data helps the reach and close; what it costs is the hold. The wrist videos say how: in every successful carry of the co-trained wrist policy the bin stays in the fisheye’s view, and in every drop it is out of view, after which the policy hesitates and commands the release (7 of 16 drops, against 2 of 10 for the reference, whose drops are slips with the jaws commanded shut). The teleop-only policy carries blind for up to 4 s; the co-trained one has lost that. Two working hypotheses are: 1) the teleop policy bridges the blind stretch from joint state, which maps onto the bin consistently in teleoperated data but not in glove episodes, whose joint actions come from IK on a human hand path; 2) the paced corpus (one duplicated frame in four, human-speed motion blur) shifts the image distribution enough to cost it that habit.

### 4 Limitations and what is next

Hardware [5] and software [6] are open; a third party has built a unit and forked the design [7]. The usable opening is 75 mm of the 86 mm mechanism, set by the span of thumb and fingers; the wrist cable can get in the way; a hard squeeze flexes the handle plate (the width label is measured, so unaffected); from one fixed viewpoint the hand hides the ball at grasp, hence the back markers (pose in 85 % of frames with them, 60 % without), and a head-worn second camera, once focused, solves it in 99 % of frames. That points at what is next: we are testing whether the glove can lose its electronics altogether, with one head-worn camera as the only collection device — no cables, nothing to synchronise — labelling the glove from a moving viewpoint and doubling as the policy’s input; the label stack already runs on head-camera footage [6].

References

[1] I2RT Robotics. Yam 6-dof arm. https://i2rt.com/products/yam-6-dof-arm, 2026.

[2] C. Chi, Z. Xu, C. Pan, E. Cousineau, B. Burchfiel, S. Feng, R. Tedrake, and S. Song. Universal manipulation interface: In-the-wild robot teaching without in-the-wild robots. In Robotics: Science and Systems (RSS), 2024.
[3] T. Z. Zhao, V. Kumar, S. Levine, and C. Finn. Learning fine-grained bimanual manipulation with low-cost hardware. Robotics: Science and Systems (RSS), 2023.
[4] R. Cadene, S. Alibert, A. Soare, Q. Gallouedec, A. Zouitine, and T. Wolf. Lerobot: Stateof-the-art machine learning for real-world robotics in pytorch. https://github.com/huggingface/lerobot, (https://github.com/huggingface/lerobot) 2024.
[5] Y. Shin. Yam-umi: hand-worn data collection device for the i2rt yam linear gripper. https: //github.com/YosubShin/yam-umi, 2026.
[6] Y. Shin. forward-cam-umi: fiducial labelling, recording and dataset tools for fixed and head-worn cameras. https://github.com/YosubShin/forward-cam-umi, 2026.
[7] vovw. tinyumi: a hand-worn, 3d-printable gripper based on yam-umi. https://github.com/vovw/tinyumi, (https://github.com/vovw/tinyumi) 2026.

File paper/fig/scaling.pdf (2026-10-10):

### forward + fovea observations

### wrist fisheye observations

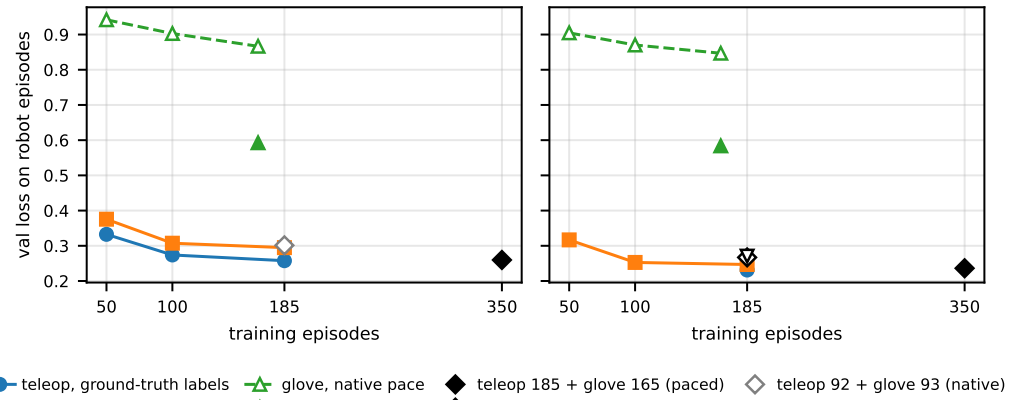
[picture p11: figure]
training episodes; val loss on robot episodes; teleop, ground-truth labels; glove, native pace; teleop 185 + glove 165 (paced); teleop 92 + glove 93 (native)

teleop, fiducial labels

glove, paced

teleop 92 + glove 93 (paced)

teleop 46 + glove 139 (paced)

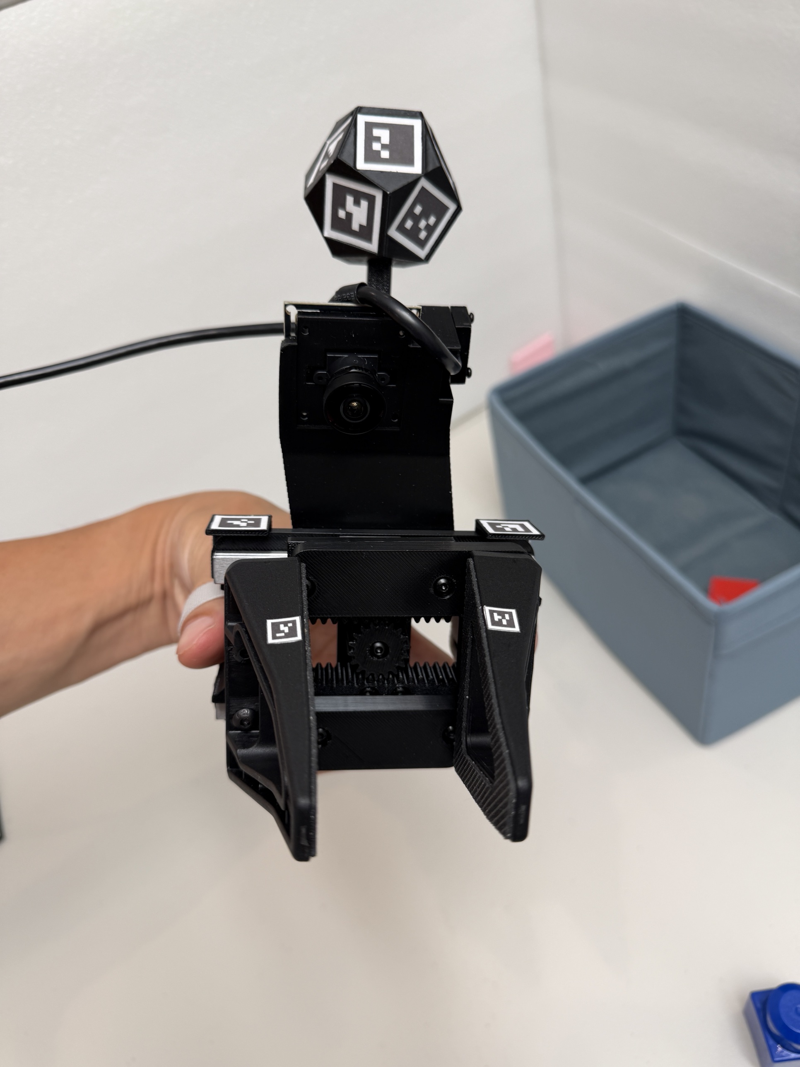
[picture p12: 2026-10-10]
paper/fig/src/glove-on-hand-front.jpg

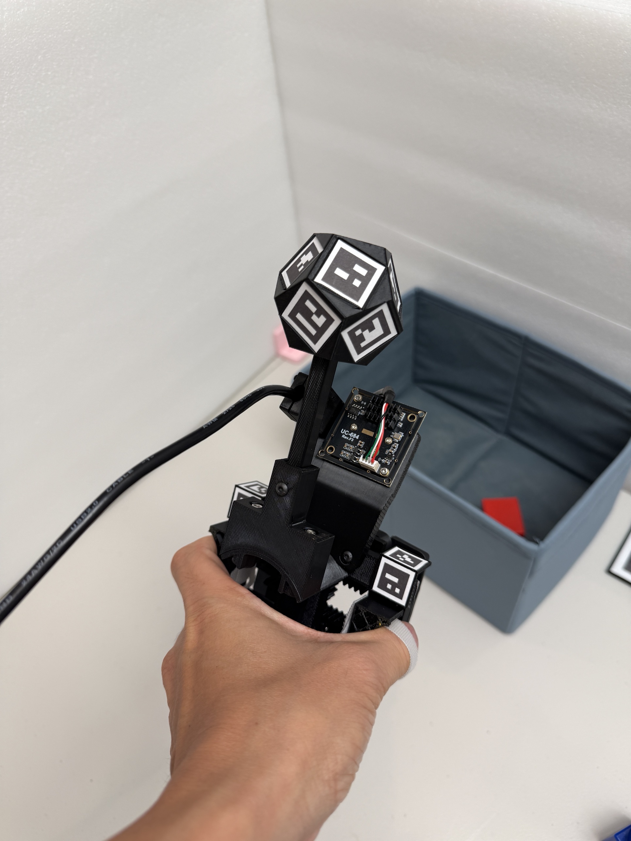
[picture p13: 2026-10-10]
paper/fig/src/glove-on-hand-top.jpg

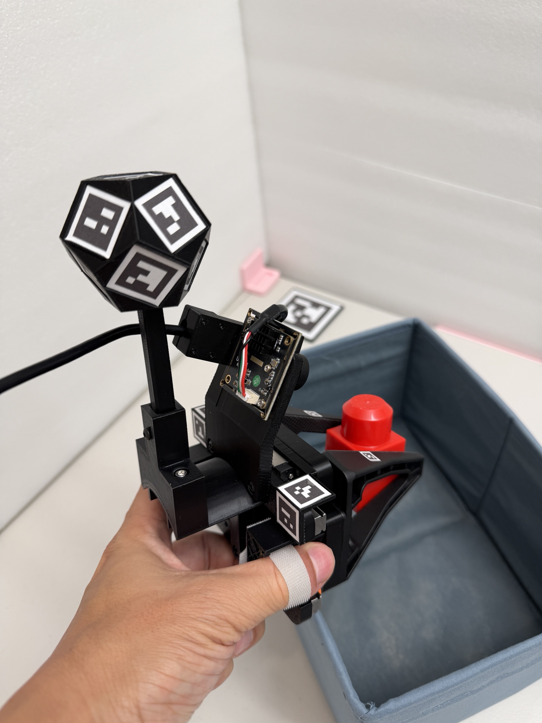
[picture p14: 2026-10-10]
paper/fig/src/glove-on-hand-side.jpg

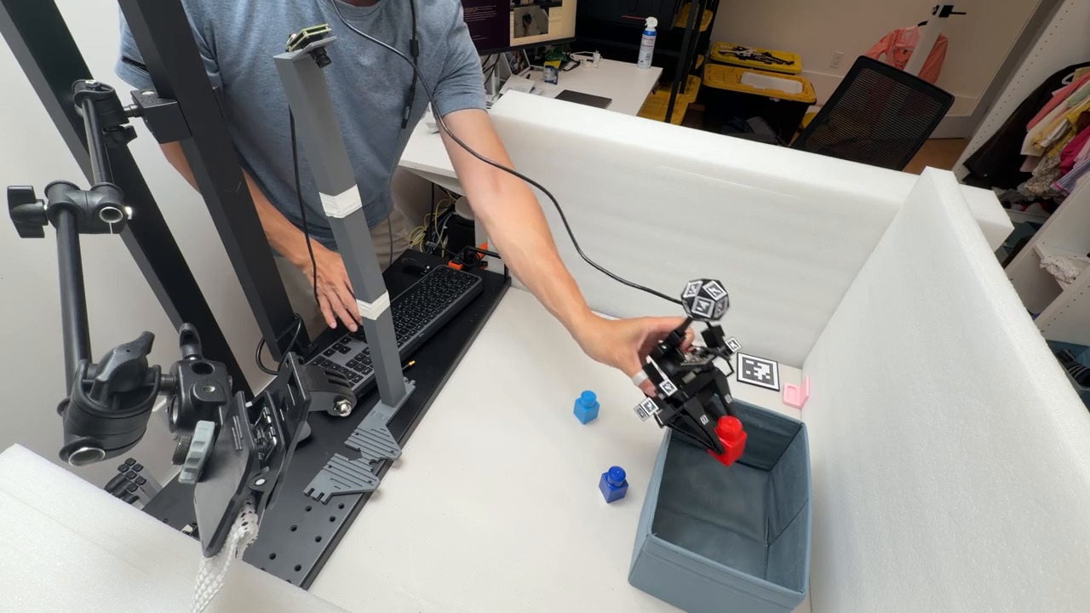
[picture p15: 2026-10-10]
paper/fig/src/collection-frame-25.2s.jpg

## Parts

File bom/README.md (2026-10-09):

# Bill of Materials

Parts needed for **one** YAM-UMI gripper. Prices are the effective per-unit cost
from the linked listing (pack price ÷ pack quantity) and are reference estimates
only — they move with shipping, region, and availability.

All quantities are confirmed against the assembled prototype.

The list is split in two. **Parts** are what you buy for this project and consume
building it. **[Prerequisites](#prerequisites)** are the workshop supplies and
tools the build draws on — a printer, filament, fastener kits, tape — which anyone
already 3D printing will have on hand. Only Parts are counted in the total, so the
headline figure reflects what this build actually costs you to add.

## Parts

### Motion

One rail and one carriage carry each jaw, so a single gripper needs **two rails
and two carriages** — two sets of the listing below. A bimanual setup needs two
grippers, so four sets.

This mirrors the YAM gripper's own mechanism, which also runs two MGN9 rails with
racks driven by a central pinion. Substituting a different rail size or a single
shared rail would break that correspondence, so treat MGN9 as a fixed choice
rather than a preference.

| Part | Qty | Unit price | Link | Total |
|---|---|---|---|---:|
| MGN9 100 mm linear guide rail + MGN9C carriage block | 2 sets | $9.99 / set | [Amazon](https://www.amazon.com/dp/B0D54LNVKX) | $19.98 |
| Ball bearing, 3 × 6 × 2.5 mm (shielded, MR63ZZ) | 2 (stacked as one pair) | $0.67 / pc ($13.29 / 20) | [Amazon](https://www.amazon.com/uxcell-3mmx6mmx2-5mm-Shielded-Miniature-Bearing/dp/B075CMRGY6) | $1.34 |
| Hook-and-loop straps, 6 in | 2 (one per finger) | $0.19 / pc ($13.99 / 75) | [Walmart](https://www.walmart.com/ip/NavePoint-6-Inch-Hook-and-Loop-Reusable-Strap-Cable-Cord-Wire-Ties-75-Pack-White/180238793) | $0.38 |

> The two bearings stack to give a 5 mm effective width. A single 3 × 6 × 5 mm
> bearing would do the same job in one piece; the pair was used simply because
> that is what was on hand. Either is fine.

> The pinion turns on an **M3 screw** through the stacked bearings, taken from the
> M3 kit in Prerequisites. Leave it slightly loose — see
> [assembly](../docs/assembly.md).

### Optics

| Part | Qty | Unit price | Link | Total |
|---|---|---|---|---:|
| Arducam 1080p fisheye USB camera (IMX291, 160°, UVC, manual-focus lens, w/ mic, 1 m cable) | 1 | $56.99 | [Amazon](https://www.amazon.com/Arducam-Computer-Fisheye-Microphone-Windows/dp/B07ZS75KZR) | $56.99 |

### Gripper tips

| Part | Source |
|---|---|
| YAM gripper tips — "Linear 4310" | **No purchase needed.** Spare tips ship with the YAM follower arm, so if you own a YAM you already have them. Only if yours are lost or damaged, I2RT sells replacements as [Gripper Tips (for Linear-Gear Style Gripper)](https://i2rt.com/products/gripper-tips-for-linear-gear-style-gripper), $69 — nylon with a rubber gripping surface, frequently out of stock. |

### Total

| | |
|---|---:|
| **Per gripper** | **~$79** |
| Bimanual pair (2 grippers) | ~$157 |

The wrist camera is roughly 72% of that. Everything else — rails, carriages,
bearings, straps — comes to about $22.

## Prerequisites

Not counted in the total above. These are shop supplies and tools rather than
parts of the design: if you own a 3D printer you almost certainly have most of
them already, and each covers many builds. Prices are listed so someone starting
from nothing can see the real outlay.

| Item | Used for | Indicative cost |
|---|---|---:|
| 3D printer | Printing the parts; PETG on a Bambu Lab X2D in the reference build | — |
| PETG or PLA filament | ~65 g per gripper (90.6 cm³ solid volume) | ~$1.30 of a $19.99 / kg spool |
| Soldering iron with heat-set insert tip | Installing the threaded inserts; many insert kits bundle one | — |
| [M3 brass heat-set inserts](https://www.amazon.com/Threaded-Inserts-Assortment-Printing-Components/dp/B0DNHLGM8D), M3 × 5 mm × ⌀4 mm | M3 threads in the printed parts | $12.99 / 100 pc |
| M4 brass heat-set inserts (match the seats in the v4 STEP file) | Gripper fastening with L bracket v4; replaces nuts | — |
| [M3 button-head screw assortment](https://www.amazon.com/dp/B0FQJQNHF5) (840 pc, 8 lengths from 6–30 mm, hex wrench included) | General fastening, plus the pinion shaft screw | see listing |
| [M4 bolt and nut assortment](https://www.amazon.com/Socket-Screw-Assortment-Stainless-Thread/dp/B01F5JI6N8) | M4 screws for gripper fastening; v4 uses heat-set inserts instead of nuts | $16.99 / kit |
| [Scotch double-sided tape](https://www.amazon.com/dp/B0035LXTYU), 1/2 in × 250 in (3-pack) | Mounting the printed ArUco markers | see listing |
| Matte white paper or label stock | Printing the marker sheets | ~$0.10 |
| Calipers | Verifying marker sheets printed at 100% scale | — |
| Small electric screwdriver *(optional)* | Driving the many small screws | — |

Buying all of these fresh runs roughly **$45–60** depending on which kits you
pick — almost all of which carries over to later builds.

A hand driver builds this fine, but a small electric screwdriver was very
convenient — quick bit changes, bits that snap in magnetically, and USB-C
charging. The [HOTO SNAPBLOQ S-A01](https://www.amazon.com/dp/B0DK4XJ9HF) is what
was used here. No affiliation.

Two of the supplies are more particular than they look:

- **Heat-set inserts.** Insert dimensions vary between sellers at the same thread
  size. The M3 seats are drawn for **M3 × 5 mm long × 4 mm OD**. L bracket v4
  also needs M4 inserts for gripper fastening; check their length and outside
  diameter against the seats in the STEP file before buying or printing.
- **Double-sided tape**, specified over glue or edge tape because full-surface
  adhesion keeps the markers flat. A marker fixed only at its edges will curl, and
  a curled ArUco marker degrades pose estimates before it looks visibly wrong.

The shopping links are for **assortment kits**; use the quantities and connection
requirements in the [assembly guide](../docs/assembly.md) when selecting screws.
All M3 screws in the base gripper and optional marker-ball assembly must be
low-profile button-head screws. For the M4 finger screws, check both handle
engagement and clearance from the opposite rack.

## Also excluded

- The **external forward-facing camera** used to observe the dodecahedral wrist
  tracker. This is a different camera from the wrist fisheye above, and it is
  needed only for marker-based pose tracking — the SLAM path uses the wrist camera
  alone. Any calibrated camera with a clear view of the workspace works, but
  coverage varies a lot with field of view; see the measured comparison in
  [`pos-tracking/README.md`](../pos-tracking/README.md). The cheaper of the two
  cameras measured there is the
  [Arducam B0591](https://www.amazon.com/dp/B0FX47YSJQ) (1080p30 HDR, 78° diagonal).
  It is an autofocus module, and its focus **must be locked** via V4L2 before use —
  see [`pos-tracking/README.md`](../pos-tracking/README.md).
- The YAM arm itself.

## Comparison

[HandUMI](https://github.com/murobotics-ai/handumi-hw) lists ~$110 per unit. The
figures are not directly comparable: that total amortises pack purchases down to a
per-piece cost — $0.07 of an M3 kit, $2.52 of a filament spool — where the list
above moves those to Prerequisites instead. Counted the same way, YAM-UMI comes to
roughly **$81** against HandUMI's $110.

The difference is structural rather than incidental. YAM-UMI drops the Feetech
servo ($13.89), its controller ($10.60) and power supply ($10.00) — about $34 —
and adds two rails and carriages (~$20). It also assumes you already own the YAM
gripper tips, which is reasonable for a rig that only fits a YAM, whereas HandUMI
prints its own tips and targets several arms.

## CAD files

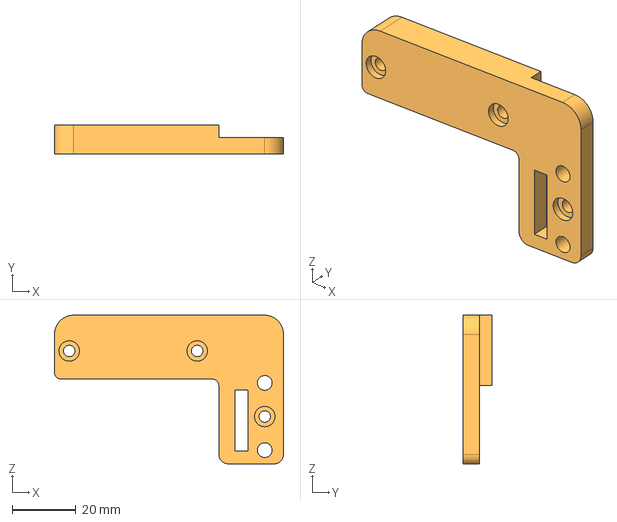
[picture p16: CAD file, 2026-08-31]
hardware/STEP/L_bracket_v3.step
71.6 x 9.10 x 46.5 mm

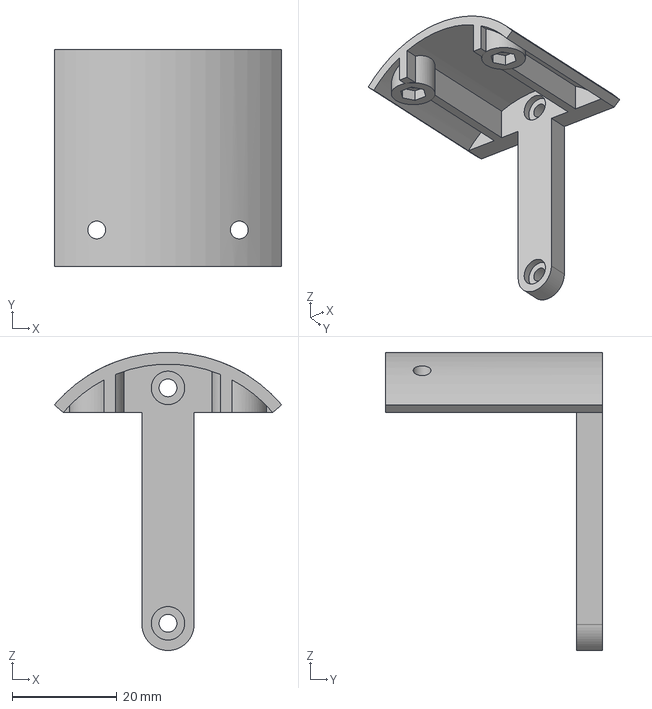
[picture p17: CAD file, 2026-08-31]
pos-tracking/wrist_dodecahedron_marker/arc_extender.step
43.5 x 41.5 x 57.0 mm

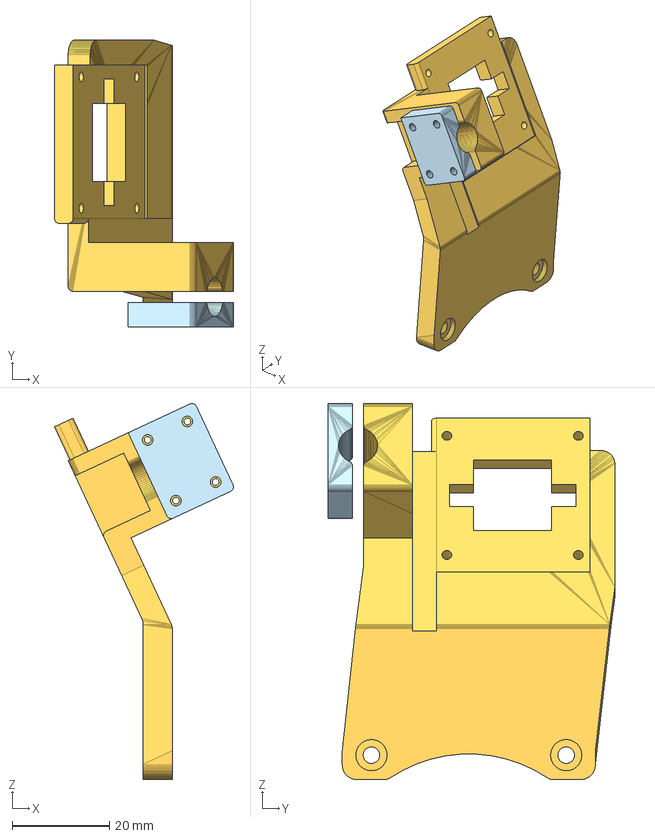
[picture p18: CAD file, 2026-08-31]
hardware/STEP/YAM_linear_gripper_fisheye_camera_mount.step
36.8 x 58.9 x 77.2 mm

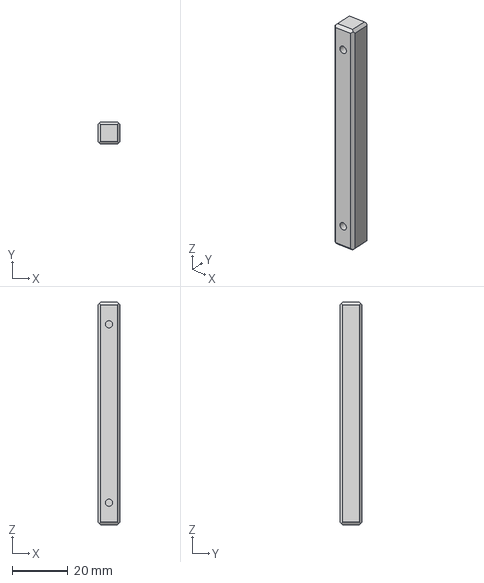
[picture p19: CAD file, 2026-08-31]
pos-tracking/wrist_dodecahedron_marker/stalk_rod_80mm.step
8.00 x 8.00 x 80.0 mm

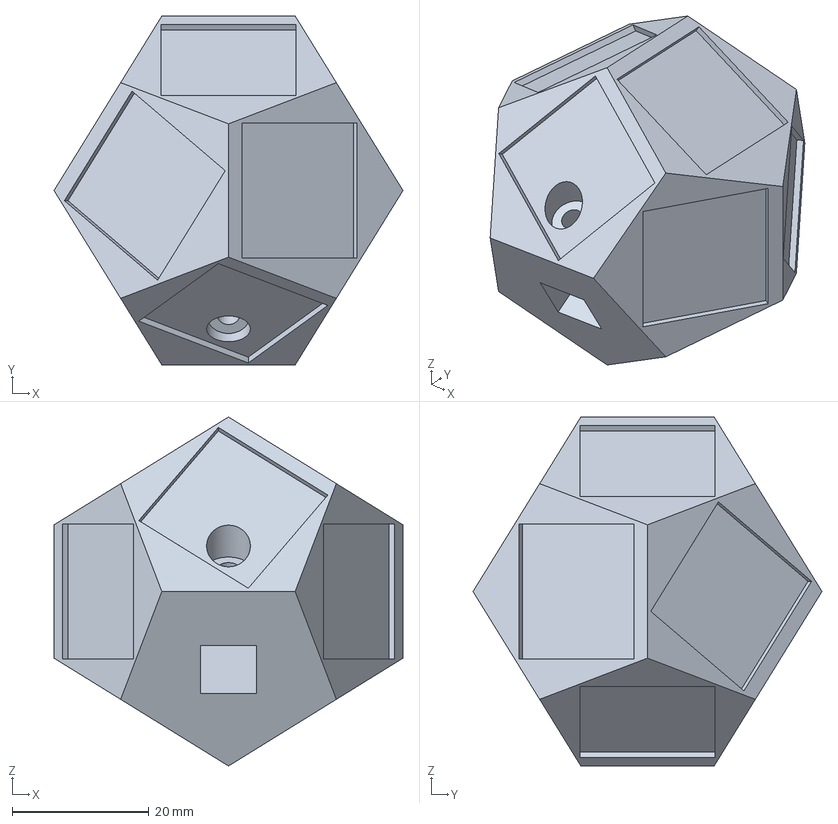
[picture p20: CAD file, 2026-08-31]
pos-tracking/wrist_dodecahedron_marker/dodeca_marker_ball_v2.step
51.1 x 51.1 x 51.1 mm

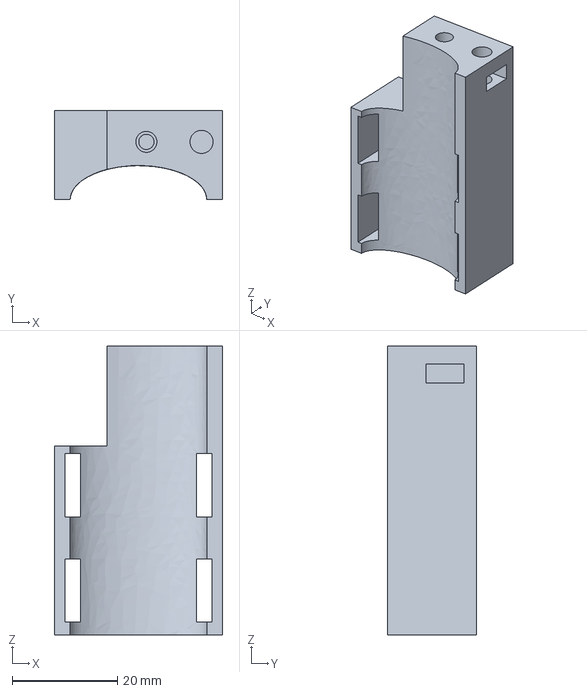
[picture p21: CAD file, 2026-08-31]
hardware/STEP/handle_v13.step
32.0 x 17.0 x 55.0 mm

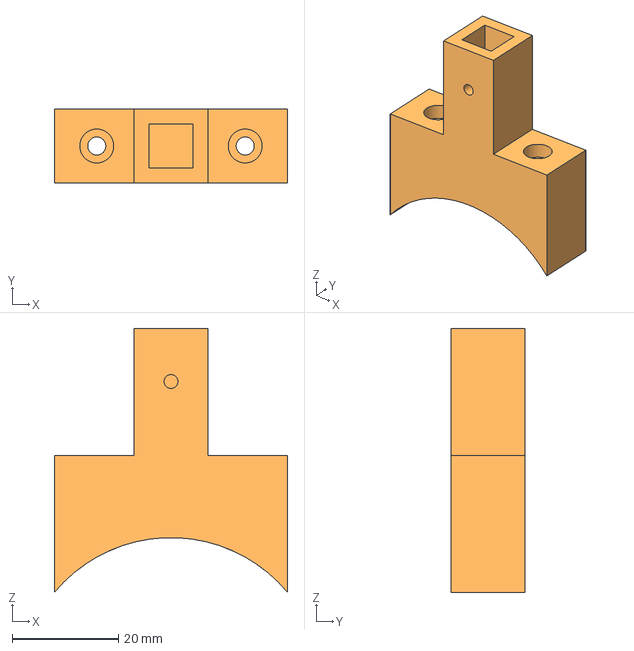
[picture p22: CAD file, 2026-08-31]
pos-tracking/wrist_dodecahedron_marker/wrist_stalk_arc_adapter.step
44.0 x 14.0 x 49.8 mm

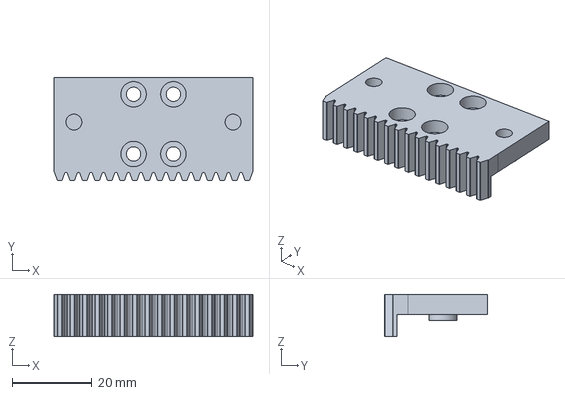
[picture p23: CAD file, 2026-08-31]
hardware/STEP/adapter_v10.step
50.0 x 25.9 x 10.6 mm

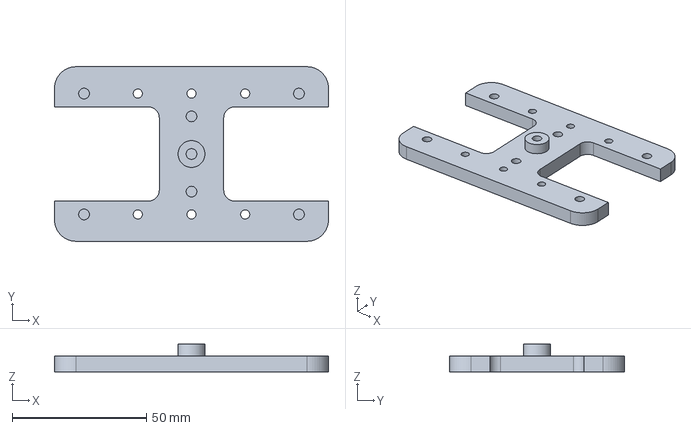
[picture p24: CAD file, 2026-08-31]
hardware/STEP/plate_v6.step
102.0 x 65.0 x 10.4 mm

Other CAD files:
hardware/STEP/pinion_z18_deep_v3.step
hardware/STEP/pinion_z18_deep_v0.step
hardware/STEP/pinion_z18_deep_v1.step
hardware/STEP/pinion_z18_deep_v2.step
hardware/STL/L_bracket_v3.stl
hardware/STL/YAM_linear_gripper_fisheye_camera_mount.stl
hardware/STL/adapter_v10.stl
hardware/STL/handle_v13.stl
hardware/STL/pinion_z18_deep_v0.stl
hardware/STL/pinion_z18_deep_v1.stl
hardware/STL/pinion_z18_deep_v2.stl
hardware/STL/pinion_z18_deep_v3.stl
hardware/STL/plate_v6.stl
pos-tracking/wrist_dodecahedron_marker/arc_extender.stl
pos-tracking/wrist_dodecahedron_marker/dodeca_marker_ball_v2.stl
pos-tracking/wrist_dodecahedron_marker/stalk_rod_80mm.stl
pos-tracking/wrist_dodecahedron_marker/wrist_stalk_arc_adapter.stl

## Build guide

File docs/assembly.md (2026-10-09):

# YAM-UMI Assembly Guide

YAM-UMI is a hand-worn, two-finger gripper. Your fingers open and close the handles, while two racks remain coupled through a central pinion; the wrist camera moves with the gripper and records the grasping area.

The assembly sequence is: **Prepare the parts → Base plate and rails → Racks and pinion → Gripper fingers and handles → Straps → Wrist camera → Optional marker-ball assembly → Markers and camera calibration → Final checks.** After installing each set of moving parts, check that opening and closing remain smooth before continuing.

The photo below shows the gripper with its wrist camera and optional marker ball. The marker ball lets a fixed external camera track the gripper's position and orientation. Install it only if you choose external-camera tracking; Section 6 describes this option and the alternatives.

Gripper with wrist camera and optional marker ball

## 0. Before You Start

### Identify the Main Parts

| Name | Shape and function | File or source | Quantity per assembly |
|---|---|---|---:|
| Base plate | H-shaped plate supporting the rails and central pinion | `plate_v6` | 1 |
| Rack adapter | Rectangular block with teeth along one edge, connecting the carriage to the gripper-finger assembly | `adapter_v10` | 2 |
| Central pinion | Meshes with both racks to couple their motion | `pinion_z18_deep_v0` through `v3`; install one variant | 1 |
| L bracket | Connects the gripper finger, handle, and rack adapter | `L_bracket_v4` | 2 |
| Finger handle | Curved finger cradle with a strap opening | `handle_v14` | 2 |
| Gripper finger | Contacts the object directly, with a rubber gripping surface on the inside | Stock YAM "Linear 4310" gripper fingers | 2 |
| Rails and carriages | Constrain the gripper fingers to linear motion | MGN9 100 mm rails and MGN9C carriages | 2 each |
| Camera mount and cover | Secure the wrist fisheye camera | `YAM_linear_gripper_fisheye_camera_mount_main` and `_cover` | 1 each |
| Wrist camera | Records the grasping area and the markers on the gripper fingers | Arducam fisheye USB camera compatible with the mount | 1 |
| Hook-and-loop straps | Secure your fingers to the handles | Straps approximately 6 inches long | 2 |

Print files are in the [gripper STL directory](../hardware/STL/). The four pinion sizes are for test fitting; install only the one that turns most smoothly. Use stock YAM gripper fingers, which do not need to be printed. Parts for the optional marker-ball assembly are listed in Section 6.

Some photos show thin rods extending to either side of the gripper, ending in square platforms. These are marker extensions for the external-camera setup and are not required for the basic YAM-UMI assembly; the photos illustrate the shared gripper structure.

### Tools and Supplies

Prepare hex tools that fit the screws, a soldering iron with a heat-set insert tip, calipers, small scissors, M3/M4 screws, heat-set inserts, thin double-sided tape, and matte paper or label stock for the markers. PETG can be used for the printed parts; remove supports and burrs, paying particular attention to the tooth gaps, mounting holes, and mating surfaces.

`M3 × 12 mm` means a screw with a nominal thread diameter of 3 mm and a length of 12 mm; the non-countersunk screws used in this guide are measured from beneath the head to the tip. **M3 and M4 are not interchangeable.** Start each screw by hand for a few turns to check that the threads engage smoothly before using a tool.

**All M3 screws in this assembly are button-head screws with a low-profile dome.** Taller socket-cap or pan heads can collide with neighbouring parts; do not substitute head styles even when the thread and length match.

Where a screw length is not specified, choose a screw of the correct thread size that fully engages its insert or nut and brings the two parts together. For the M4 gripper-finger screws, also satisfy the handle engagement and rack clearance requirements in Section 3. If a screw stops turning while a gap remains between the parts, its tip may have reached the bottom of the hole; do not force it. Use a shorter screw and check the hole alignment. Do not choose screw lengths solely from the amount of exposed thread in a photo.

### Install Heat-Set Inserts First

Heat-set inserts are internally threaded brass fittings embedded in printed parts, allowing screws to be installed repeatedly. Install them before assembling the parts, while the holes are easy to reach.

1. Lay the printed part flat and identify the insert seats. Plain through-holes are only for screws to pass through; do not press inserts into every hole.
2. Choose inserts that fit the seats. Use M3 inserts that are 5 mm long with a 4 mm outside diameter; the outside diameter and length of the M4 inserts must match the seats in the L brackets.
3. Heat the insert with the installation tip and slowly press it along the hole axis, keeping it perpendicular. Position it against the seat in the printed part so that protruding brass does not prevent adjacent parts from mating.
4. Let the plastic cool before test fitting a screw. If an insert is tilted, loose, or turns with the screw, repair the connection before continuing.

The soldering iron and freshly installed inserts are very hot; do not touch them with your hands.

## 1. Base Plate and Rails

The two parallel rails each carry a carriage for one gripper finger. First confirm the base plate's orientation, then secure the rails and check that the carriages move smoothly.

### Required Parts

| Part | Quantity |
|---|---:|
| Base plate | 1 |
| MGN9 100 mm linear rail | 2 |
| MGN9C carriage | 2, one per rail |
| Mounting screws compatible with the rail holes and base-plate inserts | 4, two per rail |

### Orient the Base Plate

Install the base plate's heat-set inserts before mounting the rails. Align the inserts with their holes so that tilted or protruding inserts do not prevent the parts from mating.

The photo below shows the rail-mounting face of the base plate. Five inserts are visible: one at each corner and one in the center. Keep this face upward when installing the rails.

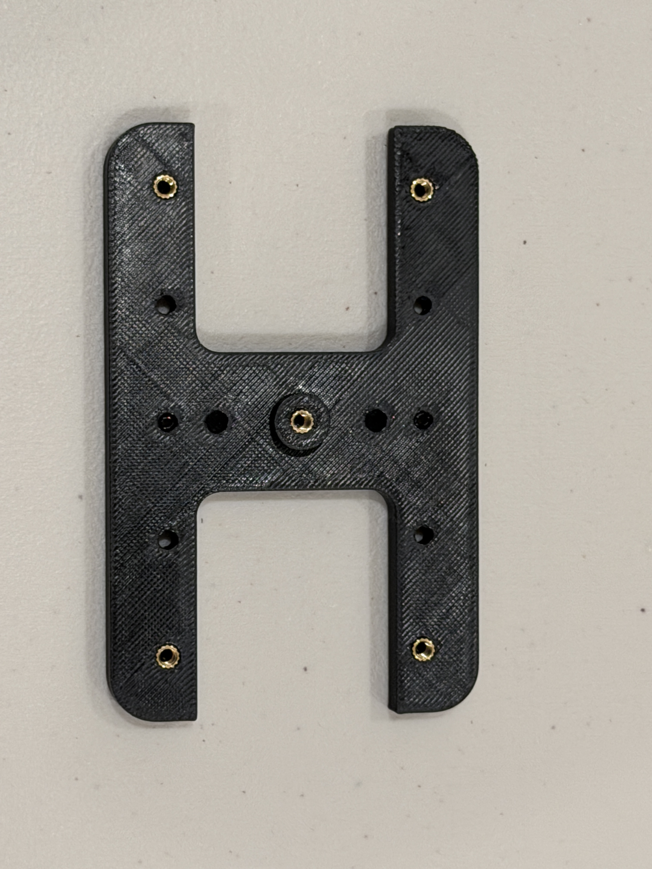
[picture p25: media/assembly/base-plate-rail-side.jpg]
Rail-mounting face of the base plate


The opposite face has four visible M3 inserts. In the orientation shown below, the two on the right secure the camera mount. The two in the center secure the optional marker-ball support assembly, which carries the [`wrist_stalk_arc_adapter` rod mount](../pos-tracking/wrist_dodecahedron_marker/wrist_stalk_arc_adapter.stl); see Section 6 for the bracket connections.

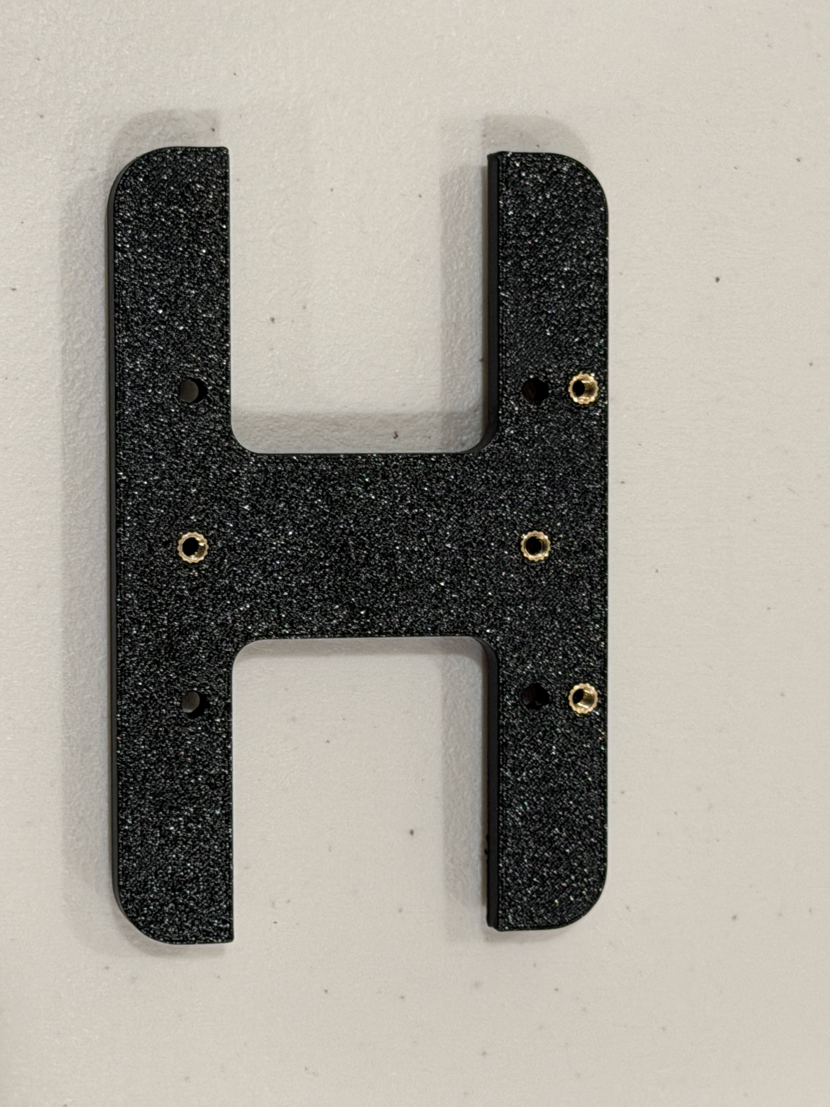
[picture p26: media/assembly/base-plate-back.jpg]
Back of the base plate


### Secure the Rails

1. Place the two rails in their mounting positions on either side of the base plate, parallel to each other, with the carriage mounting faces upward.
2. Align the rail holes with the mounting holes in the base plate. Use two screws per rail, positioned as shown below. Start the screws, then tighten them gradually until the rails sit flush against the plate.
3. Keep the rail end stops in place during assembly to prevent a carriage from sliding off the rail and shedding its ball bearings.

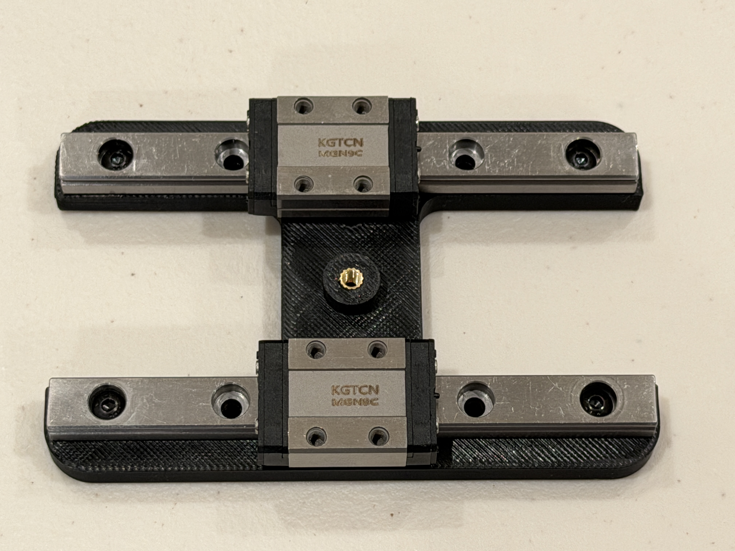
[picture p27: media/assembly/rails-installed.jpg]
Both rails and carriages installed


### Check Sliding Motion

Gently push each carriage and check that it moves smoothly throughout the usable rail travel. The rails must be secure, with no looseness between the rails and base plate. If a carriage binds, check that the rail sits flat and the mounting screws are properly seated before installing the rack adapters.

## 2. Rack Adapters and Central Pinion

Each adapter is secured to a carriage and carries one rack. The central pinion meshes with both racks, making the adapters move together in opposite directions.

### Required Parts

| Part | Quantity |
|---|---:|
| Rack adapter | 2 |
| M3 heat-set inserts for the adapters | 4, two per adapter |
| M3 × 6 mm screws for the adapter-to-carriage connections | 8, four per adapter |
| Central pinion | 1 |
| MR63ZZ bearings, 3 mm bore, 6 mm outside diameter, 2.5 mm thick | 2 |
| M3 × 16 mm screw serving as the pinion axle | 1 |

### Install the Rack Adapters

The four central mounting holes in each adapter attach it to the carriage. The heat-set inserts on either side are used later to attach the gripper-finger assembly. Install these inserts before securing the adapter to the carriage.

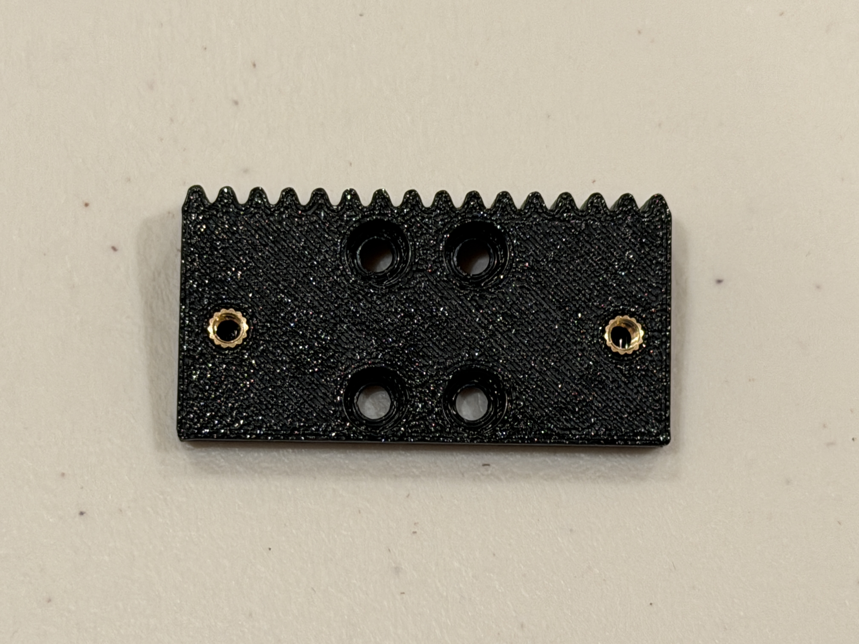
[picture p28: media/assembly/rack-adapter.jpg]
Four mounting holes and the inserts on either side of the rack adapter


1. Place one adapter on each carriage, with the toothed edges facing each other toward the center of the base plate.
2. Align the four adapter holes with the threaded holes in the carriage and secure each adapter with four M3 × 6 mm screws.
3. Move each adapter independently to check that it still slides smoothly along its rail and does not interfere with the base plate or rail ends.

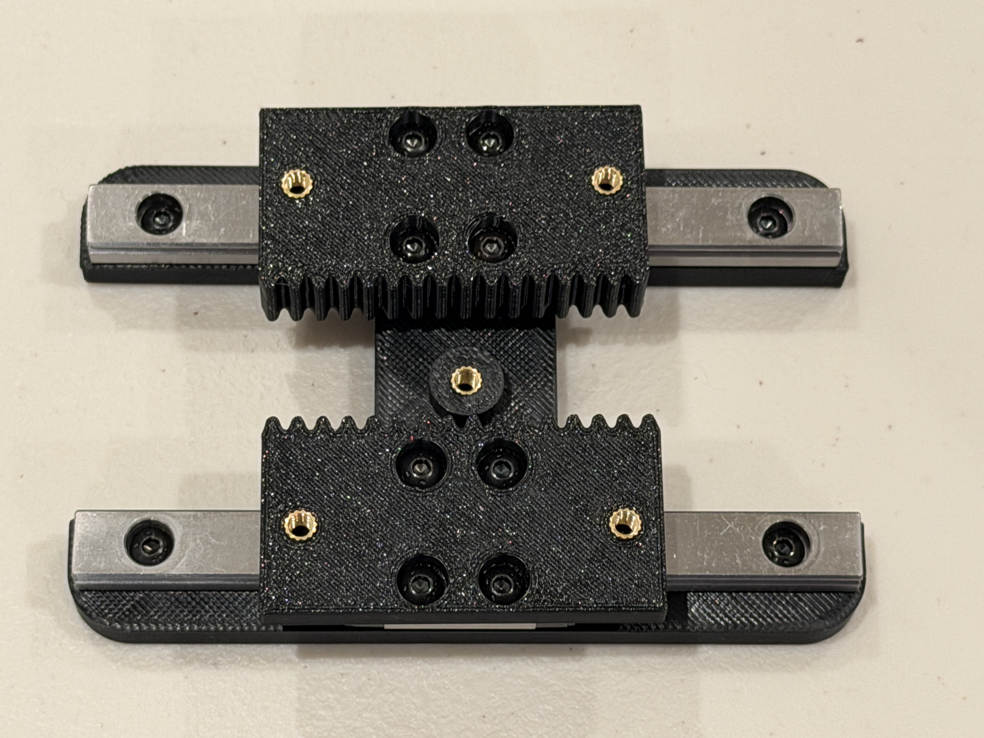
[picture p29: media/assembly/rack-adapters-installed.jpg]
Orientation of both rack adapters secured to the carriages


### Install the Central Pinion

The pinion comes in four fit variants, `pinion_z18_deep_v0` through `v3`. Test fit them and choose the one that meshes smoothly with both racks without binding.

1. Insert the two bearings one after the other into the pinion's deeper central seat, stacking them coaxially to a total thickness of 5 mm. The shallow counterbore on the opposite face accommodates the screw head; do not reverse the two faces.
2. Place the pinion between the racks with its bearing-seat face toward the base plate. Gently move the adapters and rotate the pinion until both racks mesh with it; do not force it into place while tooth tips are pressing against each other.
3. Insert the M3 × 16 mm screw from above the pinion, pass it through the bearings, and thread it into the central insert in the base plate. Keep the axle screw perpendicular to the plate so the pinion does not tilt.
4. Turn the axle screw in gradually until the pinion is stably located but can still rotate freely. Do not tighten it so far that the screw head presses against the pinion and restricts rotation.

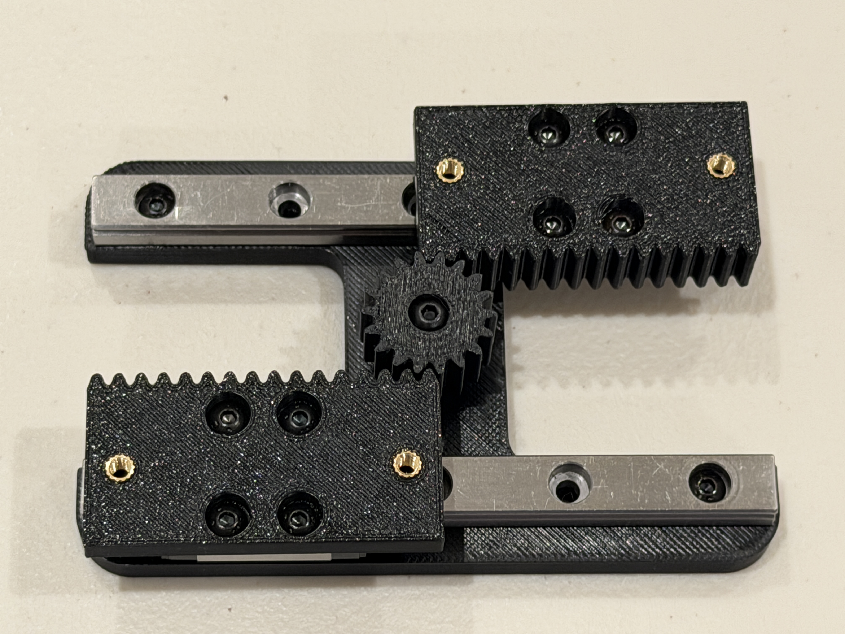
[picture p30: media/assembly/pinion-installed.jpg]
Central pinion meshing with both racks


### Check Coupled Motion

Gently push either adapter; the other should move with it in the opposite direction through the central pinion. Move them back and forth within the rail stops, checking that the pinion turns steadily, both racks remain engaged, and there is no binding or tooth skipping.

If resistance increases noticeably after installing the pinion, first check whether the axle screw is clamping the pinion, the pinion is tilted, or the pinion-to-rack fit is too tight. Confirm that the transmission moves smoothly before installing the gripper-finger assemblies.

## 3. Gripper Fingers and Finger Handles

First combine each gripper finger with an L bracket and handle to form a subassembly, then attach it to a rack adapter. The gripper fingers face the object, and the handles sit on the operator's side; the rubber gripping surfaces face each other.

### Required Parts

| Part | Total for both sides |
|---|---:|
| YAM "Linear 4310" gripper fingers | 2 |
| L brackets `L_bracket_v4` | 2 |
| Handles `handle_v14` | 2 |
| M3 heat-set inserts for the handles | 2, one per handle |
| M4 heat-set inserts for the L brackets | 4, two per bracket |
| M3 × 12 mm screws | 6, one per side to secure the handle and two per side to attach the rack adapter |
| M4 gripper-finger mounting screws | 4: one longer screw and one shorter screw per side, sized for the engagement and clearance described below |
| Washers or M4 nuts to use as spacers under the shorter screw heads | As needed to prevent the screws from protruding below the L brackets |

### Attach the Handles to the L Brackets

Each handle has a curved finger cradle, a strap opening, and mounting holes in its end face. First install an M3 insert in its seat, leaving the other hole clear for the anti-rotation fit.

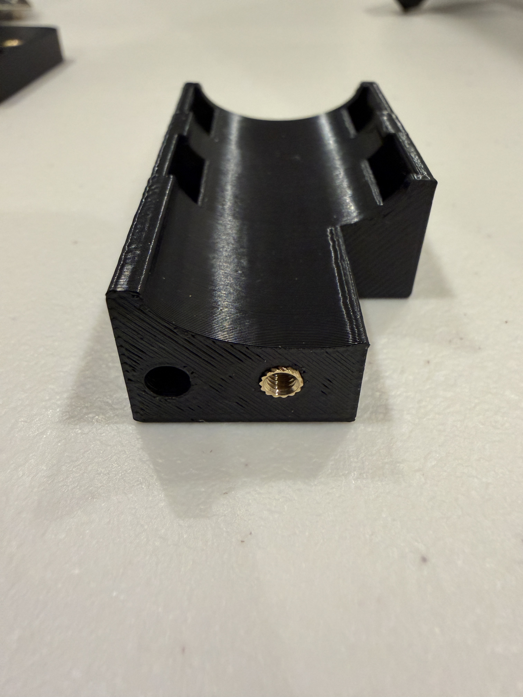
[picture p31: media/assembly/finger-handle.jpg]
Finger cradle and end-face mounting holes in the handle


1. Install M4 inserts in the two seats on the short leg of the L bracket.
2. Place the end face of the handle against the back of the bracket's short leg. Align the central M3 mounting hole and the anti-rotation hole.
3. Insert an M3 × 12 mm screw from the L-bracket side and thread it into the handle's M3 insert. Once secured, the parts should sit flush with no looseness.

`handle_v14` is secured with an M3 screw and does not require an additional M4 nut on its side.

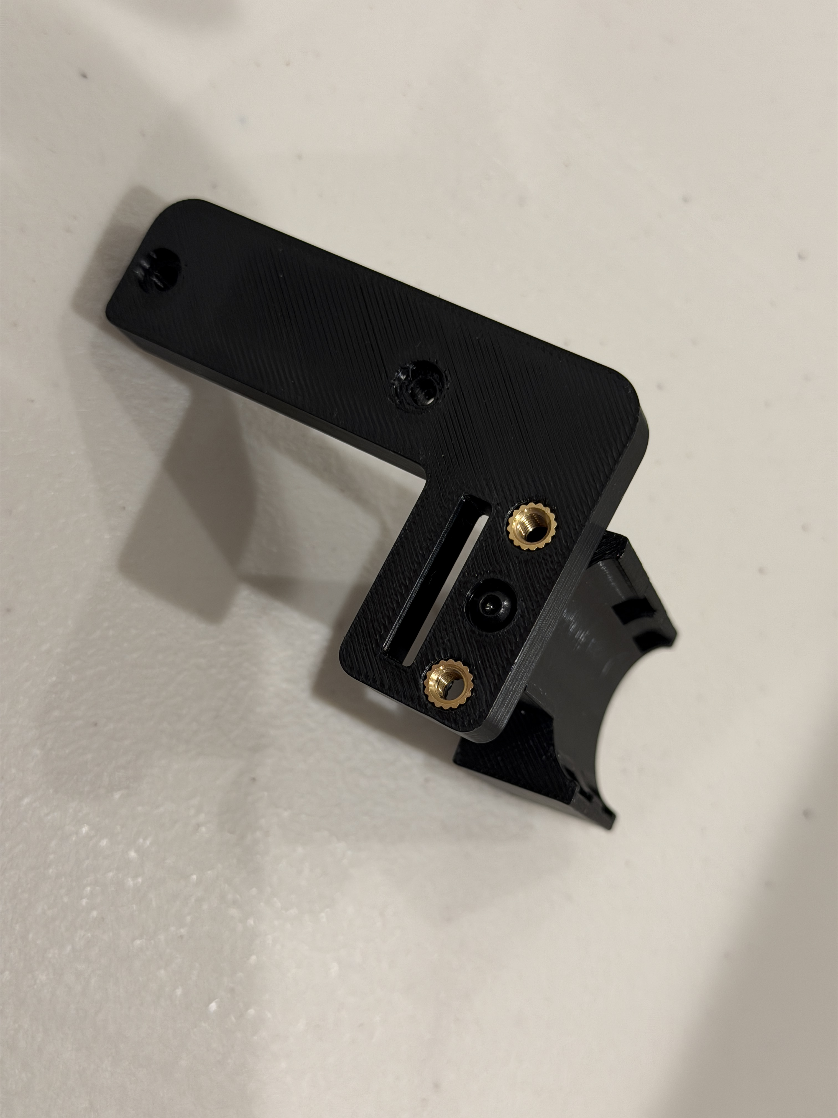
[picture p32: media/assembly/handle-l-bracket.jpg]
L bracket attached to the handle, with the M3 mounting screw in the center and M4 inserts on either side


### Secure the Gripper Fingers

1. Place the gripper finger's mounting face against the short leg of the L bracket, aligning the two mounting holes with the M4 inserts.
2. Insert two M4 screws from the gripper-finger side, using different lengths at the two holes:
   - The hole over the handle takes the **longer screw**. It passes through the finger and L bracket and extends partway into the handle to prevent rotation. Choose a length that engages the handle without bottoming out.
   - The other hole takes the **shorter screw**. It must engage the L bracket's insert without protruding below the bracket, where it would collide with the opposite rack. If the shortest available screw still protrudes, place a washer or an M4 nut under its head to take up the excess length while preserving thread engagement.
3. Start both screws in their threads, then tighten them gradually, alternating between them, until the gripper finger sits flush against the bracket. Do not use screw-tightening force to pull misaligned holes into position.
4. Assemble the other side in the same way, with the rubber gripping surfaces facing each other.

The extra plate and protruding cylinder between the screw heads and the gripper finger in the photo belong to the [forward-camera experiment](https://github.com/YosubShin/forward-cam-umi). Omit those parts for this assembly and select screw lengths for the actual finger, bracket, and handle stack.

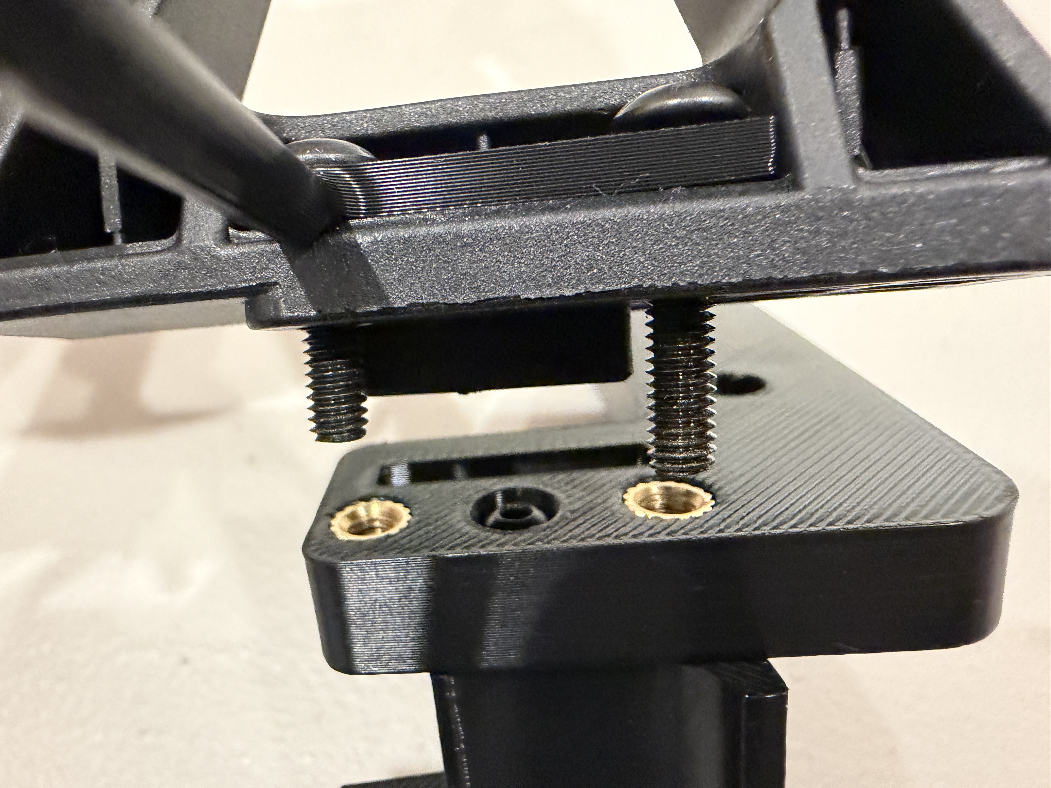
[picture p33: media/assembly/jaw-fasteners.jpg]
Connection orientation and the two M4 mounting screws between the gripper finger and L bracket


### Attach the Gripper-Finger Assemblies to the Rack Adapters

1. Align the two holes in the long leg of each L bracket with the M3 inserts on either side of its rack adapter.
2. Secure each side with two M3 × 12 mm screws. The gripper finger should move with its rack adapter, with the handle facing the operator's fingers.
3. Slowly move the gripper fingers and check for interference during opening and closing. Both sides should open and close together through the central pinion, without tooth skipping that allows one side to stop while the other continues moving.

The photos below show the open and closed positions. The marker rods extending outward on both sides are optional extensions and do not change the basic connections described here.

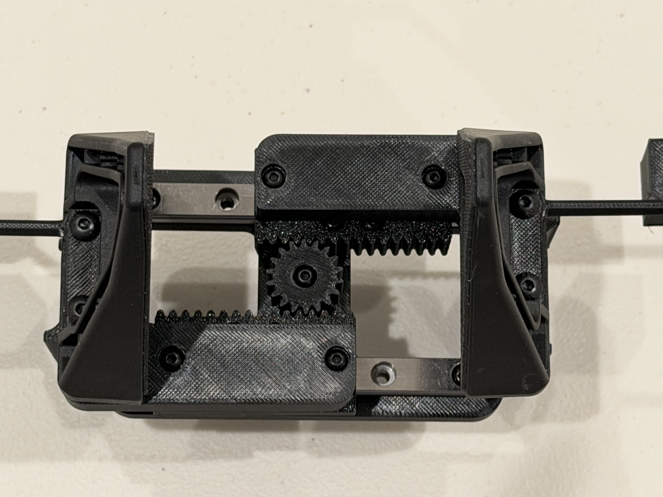
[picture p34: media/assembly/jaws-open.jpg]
Gripper fingers installed and open


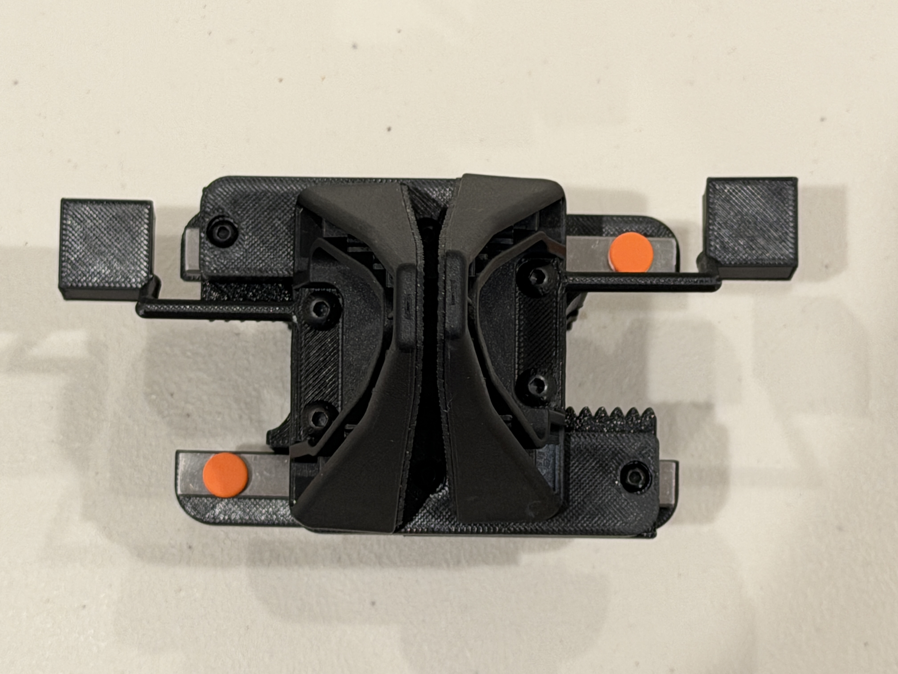
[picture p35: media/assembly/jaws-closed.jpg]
Gripper fingers installed and closed


## 4. Straps and Fit

Use one hook-and-loop strap per handle: one side for the thumb, and the other for the index finger or the index and middle fingers together.

1. Thread one strap through the strap opening on each handle to form a loop over the curved finger cradle.
2. Place your finger in the cradle, adjust the strap length, and fasten it. The strap should let you pull the handle open without constricting your finger.
3. Slowly pinch and open a few times. Check that your fingers can move the gripper naturally, both sides move smoothly, and neither your fingers nor the straps enter the moving areas of the pinion, racks, or carriages.

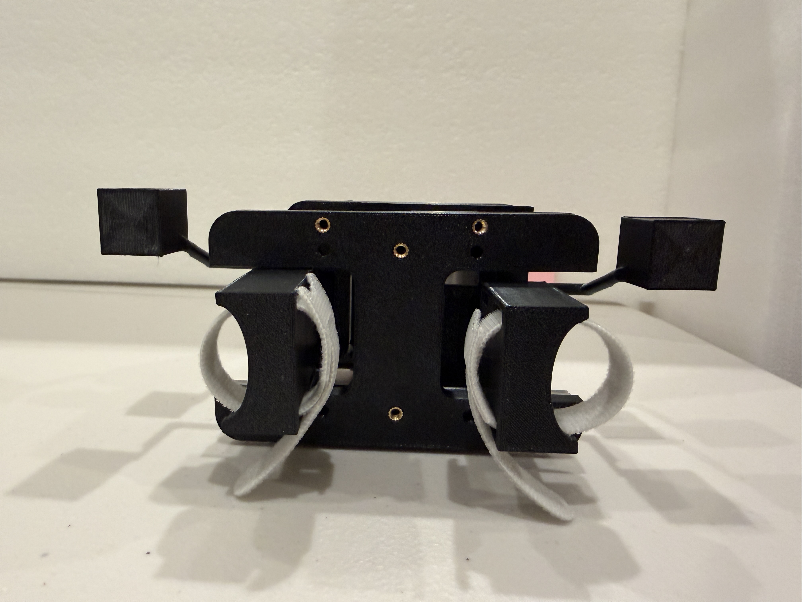
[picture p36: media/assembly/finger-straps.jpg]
Both handles with their straps fitted


## 5. Wrist Camera

The wrist camera is mounted above the base plate, with its lens facing the working area in front of the gripper fingers. The mount establishes the lens position and angle relative to the fingers. Keep the original mounting holes and structure, and do not arbitrarily add spacers that change the angle.

### Required Parts

| Part | Quantity |
|---|---:|
| Camera mount body `YAM_linear_gripper_fisheye_camera_mount_main` | 1 |
| Camera mount cover `YAM_linear_gripper_fisheye_camera_mount_cover` | 1 |
| Fisheye USB camera and cable compatible with the mount | 1 set |
| M3 × 8 mm screws for securing the mount | 2 |
| Screws compatible with the camera-board and cover mounting holes | Enough for the actual mounting holes |

### Secure the Mount and Camera

1. Place the camera mount in its matching position on the back of the base plate, with the lens-opening end above the gripper. Secure the bottom of the mount with two M3 × 8 mm screws.
2. Place the camera board in its matching seat, with the lens aligned with and protruding through the mount opening. Align the board and mount holes, then secure the board with matching screws.
3. Position the cover against its mating surfaces, checking that it does not press on camera components or cables, then secure it. Choose screw lengths that hold it securely without pressing against the circuit board.
4. Connect the USB cable and route it along the fixed structure, leaving slack for hand movement. The cable must not pass between the gripper fingers, near the pinion, or through the carriages' travel paths.

The photo below shows the mount's orientation; the camera board fits at the upper opening. The curved part below is the extension bracket for the optional tracking assembly, installed in Section 6.

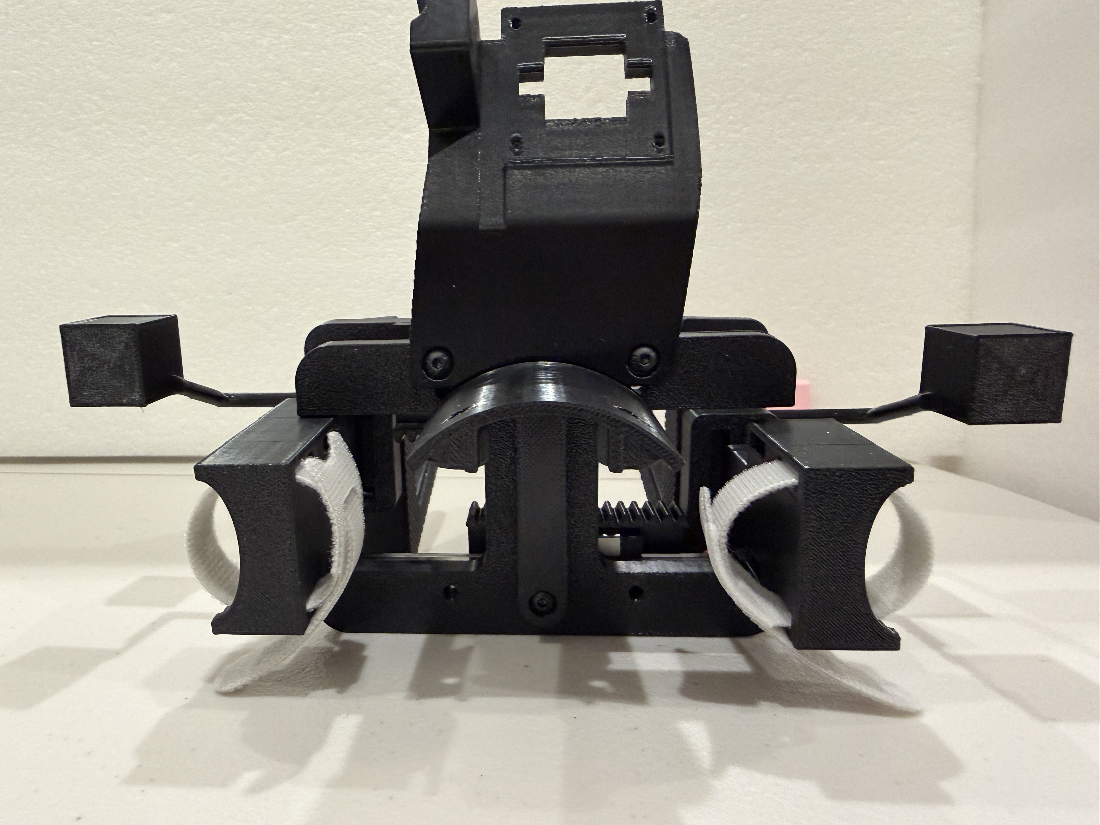
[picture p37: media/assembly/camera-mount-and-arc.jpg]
Camera mount orientation and mounting points


### Check the Camera View

Connect the camera to a computer and open its feed in a program that can preview USB cameras. Point the gripper at the actual working area and check that both gripper fingers and the target object appear in the frame. Slowly open and close the gripper and rotate your wrist, checking that the video remains continuous and the cable does not pull on the mount.

Roughly adjust the lens until the fingers and working area are clear; perform final focusing after applying the finger markers in Section 7.

## 6. Marker-Ball Tracking Assembly (Optional)

A fixed external camera reads the printed patterns on the marker ball to estimate the gripper's position and orientation. The software is in the companion [forward-cam-umi repository](https://github.com/YosubShin/forward-cam-umi). If this is your pose source, install the extension bracket, rod mount, rod, and marker ball described below.

Skip the marker-ball assembly if you use another pose source:

- **Wrist camera with visual-inertial SLAM (classic UMI):** use the fisheye camera on the gripper with the SLAM pipeline; no marker ball is needed.
- **VR hand controller:** the third-party [tinyumi Quest-controller mount](https://github.com/vovw/tinyumi/blob/main/pos-tracking/quest_mount/handumi_v1/README.md) is adapted from YAM-UMI. It requires that fork's revised base plate and mounting hardware; it does not bolt onto an unmodified `plate_v6`. This option has not been tested by the YAM-UMI authors. Follow the fork's assembly instructions for this variant.

### Required Parts

Print files are in the [marker-ball assembly directory](../pos-tracking/wrist_dodecahedron_marker/).

| Name | File | Quantity |
|---|---|---:|
| Arc extension bracket | `arc_extender` | 1 |
| Rod mount | `wrist_stalk_arc_adapter` | 1 |
| 80 mm rod | `stalk_rod_80mm` | 1 |
| Dodecahedral marker ball | `dodeca_marker_ball_v2` | 1 |
| M3 × 25 mm button-head screws for the extension-bracket-to-rod-mount connection | — | 2 |
| M3 nuts for the same connection | — | 2 |
| M3 button-head screws and inserts for the remaining connections | Sized for the respective holes | As required |

### Install the Bracket, Rod, and Ball

1. Secure the arc extension bracket to the back of the base plate, with its slender support arm along the back of the plate and its upper curved section providing a seat for the rod mount. See the photo in Section 5 for its position relative to the camera mount.
2. Seat the curved bottom of the rod mount against the extension bracket, with its square socket facing upward. Align the two mounting holes and secure the connection with **two M3 × 25 mm button-head screws and two M3 nuts**. Keep the mating surfaces flush; do not overtighten and deform the printed parts.

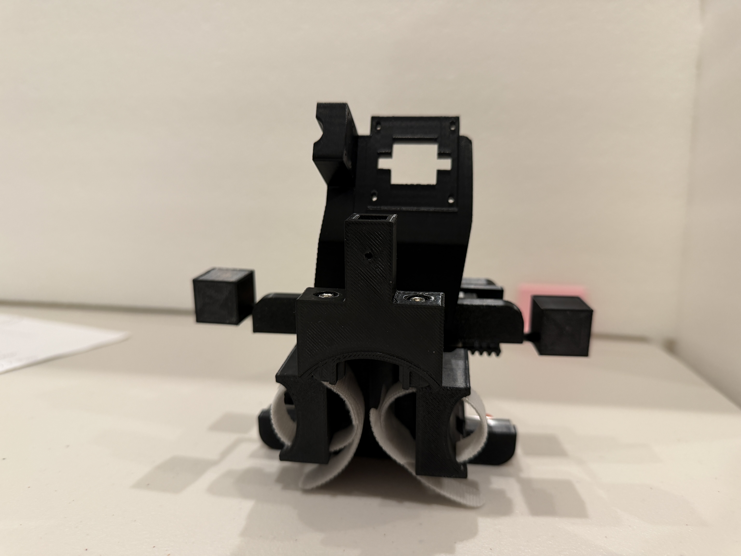
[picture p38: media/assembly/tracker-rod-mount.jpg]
Rod mount attached to the arc extension bracket, with its square socket facing upward


3. Insert the rod into the square socket, align the mounting holes, and secure it. The rod should be stable and must not wobble in the socket.
4. Attach the marker ball to the other end of the rod and secure it with an M3 screw. **Secure the ball to the rod before applying markers** so that a sticker does not cover the screw's installation point.
5. Gently hold the ball and bracket to check the connections for looseness. Put on the gripper and slowly rotate your wrist to check that the ball, bracket, camera, and hand do not collide.

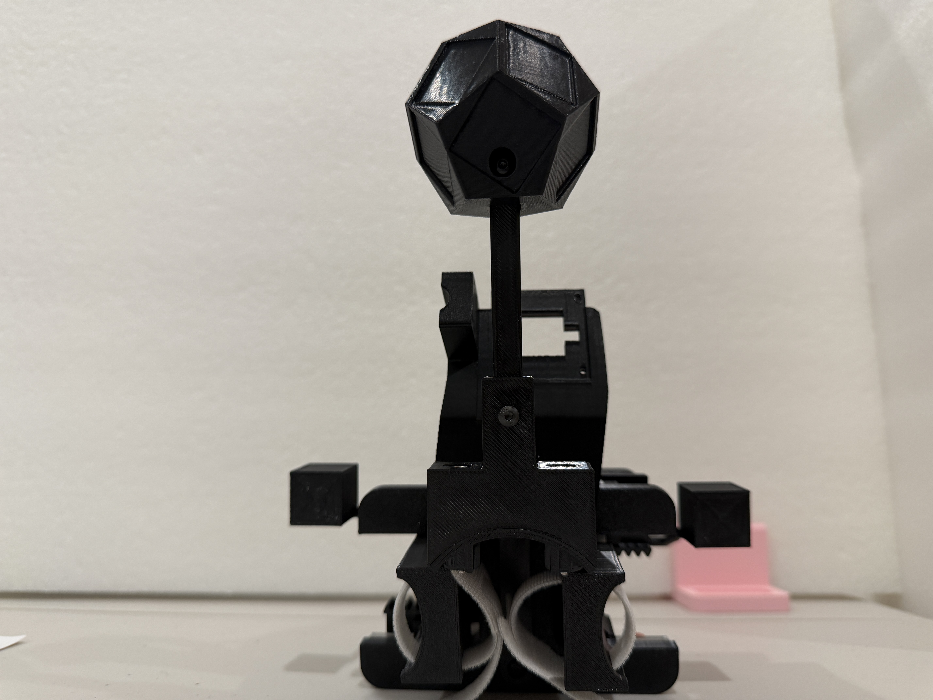
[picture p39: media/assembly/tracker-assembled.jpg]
Mechanical assembly with the rod and marker ball installed


## 7. Markers and Camera Calibration

Use the [glove marker sheet](../pos-tracking/glove_markers_v4.pdf). Apply the measurement and adhesive rules to every marker group you use. The ball-marker and forward-camera subsections apply only when using marker-ball tracking; all builds with wrist-camera aperture measurement need the gripper-tip markers.

### Measure before you cut — every marker group

Printers rescale by a few percent and the error is not visible by eye; we have seen the **same printer vary by ±5 % between two prints of the same sheet**. The solver converts the marker's printed size into distance from the camera, so a 3 % size error is a 3 % range error in every pose. For each marker group you are about to cut (ball faces, gripper tips, and the tails/bases if you use them):

1. Print at 100 % / Actual size on **matte** paper or label stock. No glossy paper.
2. **Before cutting**, caliper the **black square** of a marker — not the white outline, which is where you cut. Measure six times across different markers of the group, alternating width and height, and average.
3. Write the number down per group. It goes into your unit's marker map (`calib/marker_map_glove_<unit>.json`, see [forward-cam-umi §1](https://github.com/YosubShin/forward-cam-umi/blob/main/scripts/README.md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)) and into the ball calibration; a nominal value silently corrupts every pose.

### Apply the ball markers

From the dodecahedron group in the left column of the glove marker sheet, select the eleven ArUco markers with IDs 25–35 (`DICT_4X4_100`; nominal 15 mm black square, 19.5 mm tile including the white border). Apply one marker per face to eleven faces, no duplicate IDs. The ID-to-face layout is free — it is recovered by the ball calibration — so **do not move or swap a marker after calibrating**: a re-stuck marker means a re-calibrated ball, and each ball's calibration stays with that physical unit.

Adhesive matters more than it looks, because the solver measures the marker's **corners**:

- **No glue.** Glue curls the paper's edges as it dries, exactly where the corners are.
- **No tape over the marker face** and no glossy surface: reflections and refraction move the corners.
- Use **thin double-sided tape** covering the **entire** back of the marker: tape the uncut sheet region first, then cut the marker out through paper and tape together, so every edge is bonded with no loose margin. Keep each marker flat on its own face; never bridge an edge between two faces.

### Apply the gripper-tip markers

Two **6 mm AprilTag 16h5 markers, IDs 2 and 3**, go on the **top of the gripper fingers**, one per jaw, where the wrist camera sees them; we placed them **30 mm from the root of the finger**. They give the wrist camera a metric reading of the jaw opening, so they are needed for wrist-camera policies too, not only for ball tracking. Same rules as above: caliper before cutting (6 mm nominal), matte paper, full-back double-sided tape, no glue, nothing over the face. Both tips must stay visible to the wrist camera across the full opening; check with [`tag_contrast.py`](https://github.com/YosubShin/forward-cam-umi/blob/main/scripts/tag_contrast.py) after installing.

The tails and bases groups in the right column of the sheet belong to the forward-camera extension (occlusion backup for the ball) and are not needed otherwise.

### The forward camera: mount, focus, calibrate, solve the ball

Marker-ball tracking needs one fixed camera over the workspace (we use an Arducam B0587 4K). The full procedure with commands is [forward-cam-umi, steps 2–6](https://github.com/YosubShin/forward-cam-umi/blob/main/scripts/README.md); in short:

1. **Mount it rigidly** so it cannot move between calibration and recording. Aim it at the full working area so the ball stays in frame when the gripper is raised or rotated, with headroom above the workspace (the ball is the highest point on the gripper), and avoid prolonged occlusion by your hand or the camera cable.
2. **Focus** with the live meter ([`focus_tune.py`](https://github.com/YosubShin/forward-cam-umi/blob/main/scripts/focus_tune.py)) on a marker at working distance, then mark the barrel; refocusing later means recalibrating.
3. **Intrinsics** from a ChArUco board ([`calibrate_uvc.py`](https://github.com/YosubShin/forward-cam-umi/blob/main/scripts/calibrate_uvc.py)), with the board's squares calipered like the markers.
4. **Solve the ball** from one slow rotation take ([`bundle_dodeca.py`](https://github.com/YosubShin/forward-cam-umi/blob/main/scripts/bundle_dodeca.py), [`bundle_dodeca_ideal.py`](https://github.com/YosubShin/forward-cam-umi/blob/main/scripts/bundle_dodeca_ideal.py)), then the jaw-marker geometry ([`calibrate_gripper_bundle.py`](https://github.com/YosubShin/forward-cam-umi/blob/main/scripts/calibrate_gripper_bundle.py)). Store the results with the unit.

Measured on the real robot, this stack tracks the gripper to 7.7 mm / 1.7° median against the arm's own kinematics — see [`pos-tracking/dynamic-accuracy.md`](../pos-tracking/dynamic-accuracy.md).

### Set the Wrist Camera Focus

After applying the gripper-tip markers, at the working distance of the gripper fingers and the object, slowly rotate the lens barrel until the marker edges are sharp. Check once with the gripper open and once with it closed, then secure the lens locking ring.

**Finish focusing before calibrating the camera.** Calibration establishes the relationship between image coordinates and physical geometry; turning the lens again changes the imaging parameters, so a focal-length adjustment requires recalibration.

## 8. Final Checks

First check the gripper without an object, then grasp something light and non-fragile. Pass each check before preparing for data collection.

| Check | Procedure and pass condition |
|---|---|
| Fixed connections | Gently wiggle the gripper fingers, handles, and brackets; no connection is loose, and no insert turns with its screw |
| Coupled opening and closing | Slowly open and close the gripper several times; both sides move together, the pinion stays engaged, and there is no binding or tooth skipping |
| Travel and end stops | Adapters do not hit fixed parts, shorter M4 screws do not protrude into the opposite rack, and carriages cannot leave the rails |
| Grasping contact | Both rubber gripping surfaces contact a light object, with no tilting of the gripper fingers |
| Fit | Straps do not constrict your fingers; you can open and close the gripper naturally without touching the transmission |
| Wrist camera view | The camera is secure, video is continuous, and the fingers and working area are clearly visible |
| Finger markers | Both distinct IDs decode throughout opening and closing; markers are flat, matte, fully bonded, and uncovered |
| Printed dimensions | Each used marker group has six black-square measurements averaged and recorded for this unit; calibration uses those measured sizes |
| Cables | Rotating your wrist or opening the gripper does not pull on connectors or draw cables between moving parts |
| Optional marker ball | The ball and rod mount are secure, stickers are flat with distinct IDs, and the ball remains within the external camera's view during operation |

After the hardware checks, complete calibration and a trial recording with your chosen tracking software. For external-camera tracking, use the companion procedure linked in Section 7 and keep the calibration files with the unit. Keep camera focus, camera mounting, marker positions, and bracket connections unchanged after calibration; if any of these change, repeat the affected calibration before recording data. Completing the mechanical assembly does not by itself provide usable pose or aperture data.

## 9. Troubleshooting

| Symptom | Checks and corrective action |
|---|---|
| A carriage slides smoothly on its own but becomes stiff after the adapter is installed | Check whether the adapter's underside sits flat, mounting holes align, or the screws bottom out before securing the adapter |
| Resistance increases noticeably after the pinion is installed | Check whether the axle screw presses against the pinion or the pinion is tilted; try a pinion size that meshes more smoothly |
| The two sides do not move together, or teeth skip | Check that the toothed edges face each other, the pinion meshes with both racks, and the adapters and pinion are secure |
| Motion binds after the gripper fingers are attached | Check that the shorter M4 screws do not protrude below the L brackets; use shorter screws or spacers under their heads while preserving thread engagement |
| A screw will not turn further but a gap remains between the parts | Check for a bottomed-out screw, misaligned holes, or remaining print supports; do not force the screw |
| An insert turns with its screw | Stop tightening and repair the insert mounting; replace the printed part if its insert seat is damaged |
| A marker is obscured when the gripper closes | Use the camera preview to identify the obstruction, reposition the marker within the flat area, and recheck detection over the full travel; repeat the affected geometry and aperture calibration if the marker moved |
| Marker edges are blurred or reflective | Check focus, paper flatness, and lighting; use matte paper with no tape over the face. Recalibrate the camera after refocusing, and the affected marker geometry after replacing a marker |
| The marker ball leaves the frame or is hidden by your hand | Adjust framing to leave room for lifting the gripper, and check the bracket's position relative to your hand; repeat the affected extrinsic calibration if the camera or bracket moves |

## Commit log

2026-08-31 Initial commit: YAM-UMI hardware design
    Hand-worn UMI-style data collection device for the I2RT YAM arm's linear
    gripper. Mirrors the YAM gripper geometry and reuses its wrist camera mount so
    the camera-to-tip extrinsic matches deployment, and recovers aperture from ArUco
    fiducials instead of a servo encoder.
    Includes gripper body parts (STEP + STL), the dodecahedral wrist tracker,
    aperture tails, marker sheets, BOM, and printing/assembly docs. Several BOM
    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
    [L_bracket_v3.step, L_bracket_v3.stl, YAM_linear_gripper_fisheye_camera_mount.step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]
2026-08-31 docs: credit UMI's observation-gap principle, frame contribution as direction
    The README implied camera-extrinsic parity was this project's insight. It is
    UMI's own stated design principle. Reframe the contribution as the direction of
    adaptation — UMI adapts the robot to the interface, YAM-UMI adapts the interface
    to the robot — and correct the HandUMI characterisation to its actual approach.
2026-09-16 Certify dynamic tracking and absolute robot-frame pose accuracy
    Add pos-tracking/dynamic-accuracy.md: the dodecahedral ball measured
    against YAM joint-encoder ground truth during full-speed teleoperated
    manipulation (30 episodes, ~23k frames): 7.7mm median / 22.7mm p95 /
    1.7deg at a 13cm tool point, pose solved in 98.5% of frames. Resolves
    both standing caveats: settled-holds-only, and the unresolved absolute
    pose (the 14%/9% discrepancies were extrinsics, fixed by a
    calibrateRobotWorldHandEye solve harvested from ordinary episodes,
    4.8mm/0.85deg residual). Documents detection settings (APRILTAG refine,
    errorCorrectionRate=1.0 id-swap-safety argument), failure geometries
    (frame-edge clipping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
2026-09-16 Document the B0587 4K low-light camera and the fast-shutter recipe
    Add the camera that produced the dynamic-accuracy results to the
    performance section: intrinsics, pair RMS, no measured speed ceiling,
    99.97% session detection. Explain the motion-blur unlock (0.2ms shutter
    made viable by low-light silicon; blur, not frame rate, is what kills
    fiducial decoding) and the four traps: readback lies / behavioral
    verification, tone-mapping ISPs hiding exposure, inert focus_absolute
    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
2026-09-23 Move robot-mount tracker parts to forward-cam-umi; switch to glove_markers_v4 sheet
    Tip markers are now AprilTag 16h5 and ball markers use DICT_4X4_100 IDs 25-49.
    Document the arc-mount tracker assembly and link forward-cam-umi.
    [retainer_radial_tab.step, retainer_radial_tab.stl, wrist_stalk_adapter_v3.step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]
2026-10-10 Paper (CoRL 2026 UMI Arena, device track): LaTeX source, figures, PDF; workshop video; links in README
    Claude-Session: https://claude.ai/code/session_01SYB2Z7ZfRybzoJTN4ZACnB
2026-10-10 Labels: a second rig needs only taped tiles (free base is 20-40 deg off in yaw; 20 deg costs 3%); duplicated sentences removed to stay on 4 pages
    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
2026-10-10 Rollouts: camera-bump sentence removed
2026-11-01 docs: squeeze-force plan: spring glove printed, 4.5 kg full-squeeze reading
    Claude-Session: https://claude.ai/code/session_01TFr2PmfTwrKZZkFSHt6rPt
2026-11-01 docs: spring glove weighs 410 g and lifts a half gallon without sagging
    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
